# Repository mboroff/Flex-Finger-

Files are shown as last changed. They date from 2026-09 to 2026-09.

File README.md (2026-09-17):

# Flex Radio Mechanical Button Actuator (Linear Stepper Version)

A stepper-driven mechanism that physically presses the front-panel power button on a FlexRadio Flex 6xxx or 8xxx series software-defined radio (SDR), allowing it to be powered on, powered off, or force-reset (long hold) remotely from a Raspberry Pi.

This version replaces the original rotating servo-driven arm concept with a **28BYJ-48 stepper motor** paired with a linear rack-and-pinion finger, delivering high precision, smooth linear movement, and eliminating positional jitter.

---

## 📟 How the Radio's Button Behaves

The radio's front button behaves based on duration and state:

| Action | Result |
|---|---|
| Momentary press while off | Radio powers on |
| Momentary press while on | Radio powers off |
| Press and hold (while off) until the button glows white (~6.0s), then release | System factory reset |

The driver software handles two routines: a **momentary press** (power toggle) and a **long hold-then-release** (system reset). Both actions are "move finger onto button, dwell, move finger back," with the wait time being the only operational difference.

---

## 🏗️ Hardware & Wiring

### Parts List
- **Controller:** Raspberry Pi 4B (installed natively in `/home/pi`)
- **Motor Assembly:** 28BYJ-48 stepper motor + ULN2003 driver board
- **Enclosure & Mechanism:** 3D printed linear rack, pinion gear, and custom case (printed in PETG)
- **Fasteners:** M3 hardware for mounting the brackets near the radio panel
- **Power & Logic:** 4x jumper wires (Pi GPIO -> ULN2003 IN1-IN4), plus 5V/GND for the driver board.
  *(Note: Power the ULN2003 board from the Pi's 5V pin or a separate 5V supply if you see brownouts — the motor can pull enough current to reset the Pi on some setups).*

### Wiring Diagram

```
Raspberry Pi (BCM)      ULN2003 board
-------------------     -------------
GPIO17  -------------->  IN1
GPIO18  -------------->  IN2
GPIO27  -------------->  IN3
GPIO22  -------------->  IN4
5V      -------------->  VCC (motor supply)
GND     -------------->  GND
```

Pin mappings match the configuration variables in `software/stepper.py`. Update the code pins array if you wire the hardware differently.

---

## ⚙️ Mechanism & OpenSCAD Modeling

The 28BYJ-48 has a ~1:64 internal gear reduction, which provides high holding torque and precise positioning at low speed—ideal for a push-finger that needs to land reliably in the same spot every time. 

### 1. Actuator Mechanism (`finger.scad` / `gear.scad`)
- **The Linear Finger (`finger.scad`):** An L-shaped rack track with customized gear mesh teeth. The short edge of the "L" hangs over the front panel of the radio cabinet directly above the power button. 
- **The Drive Pinion Gear (`gear.scad`):** A custom 13-tooth gear designed with a specialized trapezoidal profile. It features a complete through-hole socket with a dual-flat profile (Double-D shape) matching the machined output shaft of the stepper motor perfectly.

### 2. Custom Electronics Enclosure (`enclosure.scad`)
- A 2.5-inch square custom travel box with integrated alignment pin standoffs configured specifically to securely seat the ULN2003 board.
- Includes built-in structural wire drop slits on opposite side walls and a custom friction-fit ventilation lid featuring a clean hexagonal cutout pattern for active airflow.

### Print Settings (PETG)
- **Nozzle Temp:** 230-240 °C, **Bed Temp:** 80-85 °C
- **Perimeters:** 3-4 walls, **Infill:** 20-25% (parts are low-load)
- **Supports:** No supports needed on any part as drawn (flat bottoms, bore facing up)
- Print the pinion gear with the bore axis vertical for precision accuracy on the Double-D profile.

---

## 💻 Software & Script Configuration

The control software is divided into a low-level driver and an automated action script wrapper:

*   `stepper.py` — Low-level motor driver. Takes step count + direction as parameters (CLI or import), and drives the ULN2003 half-step sequence.
*   `button_actions.py` — High-level automated actions (`power_toggle()`, `system_reset()`), containing your physical calibration constants.

### Direct Command-Line Examples

**Low-Level Rotation Example via `stepper.py`:**
```bash
python3 stepper.py --steps 512 --direction cw
```

**High-Level Button Automation Examples via `button_actions.py`:**
```bash
# Execute a standard power cycle toggle
python3 button_actions.py power

# Execute a system factory reset sequence (Requires terminal confirmation)
python3 button_actions.py reset
```

---

## 🔬 Calibration Procedure

Because the stepper motor is driven open-loop (no encoder), the "home" and "pressed" positions are step counts you calibrate once to match your printed geometry:

1. Home the linear finger by hand (with the motor unpowered) so it sits just clear of the physical radio button. Note this as position 0.
2. Run `stepper.py` with small step increments in the advance direction until you find the step count that fully depresses the button. Record this value as `PRESS_STEPS`.
3. Update `PRESS_STEPS` and `PRESS_DIRECTION` in `button_actions.py`.
4. Test the `power_toggle` action first (safe to get wrong). Only test the `system_reset` route once you are fully confident—an unintentional 6+ second hold will wipe your radio settings.

---

## 📂 Repository Structure

```
flex-button-bot/
├── README.md
├── hardware/
│   ├── enclosure.scad          # Custom ULN2003 case & hex lid
│   ├── finger.scad             # Linear moving rack-finger track
│   └── gear.scad               # Double-D shaft drive pinion gear
└── software/
    ├── stepper.py              # Low-level ULN2003 motor driver
    └── button_actions.py       # High-level macro action script
```

---

## ⚠️ Safety Notes

- **Stuck State Risk:** The reset action holds the button down for several seconds. If the software crashes or loses power while the arm is advanced, it could hold the radio in a perpetual reset loop. Consider a manual mechanical fail-safe (like a physical return spring) if running completely unattended.
- **Coil Management:** `stepper.py` always releases all coils in its `cleanup()` phase (including on unexpected crash exceptions), ensuring the motor never sits under continuous holding current when idle.

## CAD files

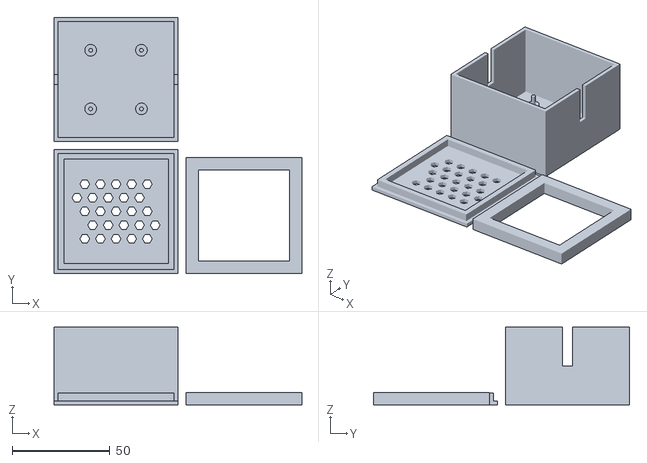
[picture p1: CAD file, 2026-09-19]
ControlBoxRing_google_V6.stl
126.9 x 131.0 x 39.7

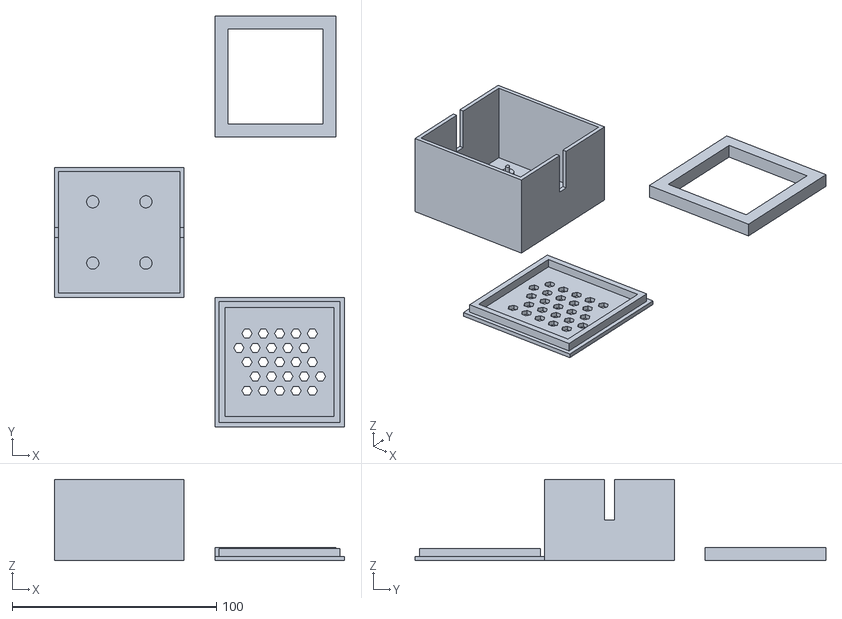
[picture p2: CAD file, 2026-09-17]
ControlBoxAndRing_google_V3.stl
142.0 x 201.2 x 39.7

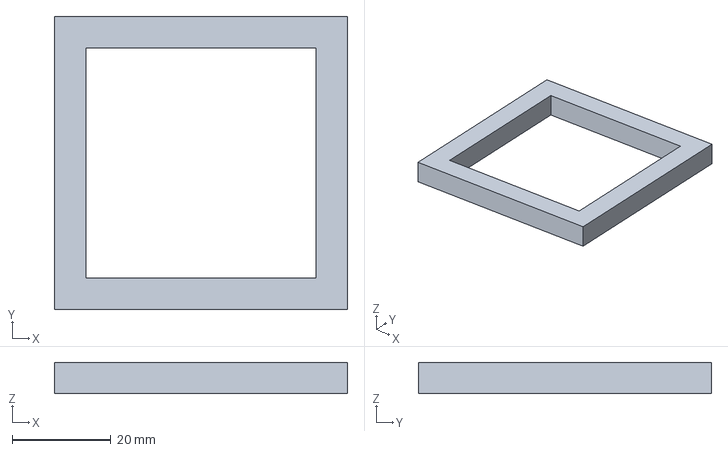
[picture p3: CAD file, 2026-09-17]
ControlBoxRing_google_V1.3mf
59.2 x 59.2 x 6.35 mm

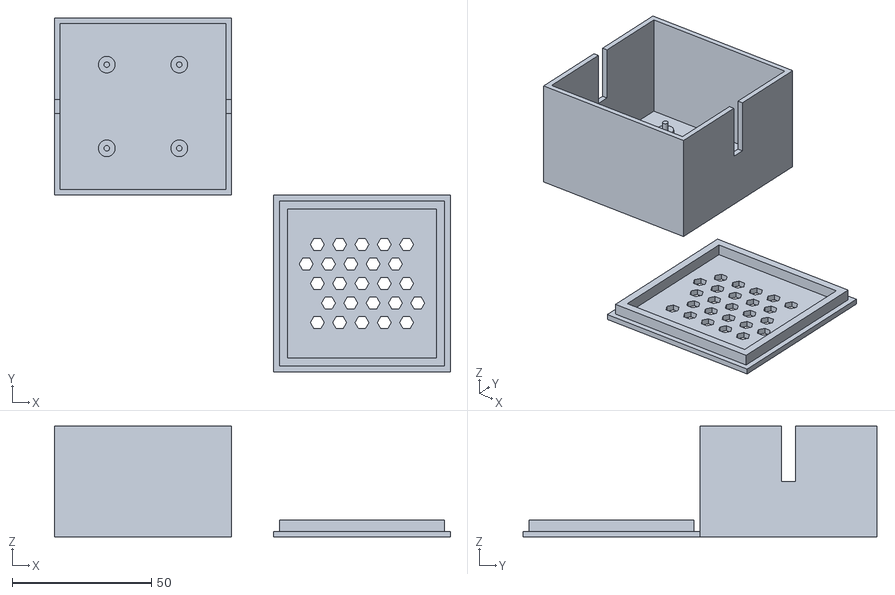
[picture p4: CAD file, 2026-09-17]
ControlBoard_Google_V2.stl
142.0 x 127.0 x 39.7

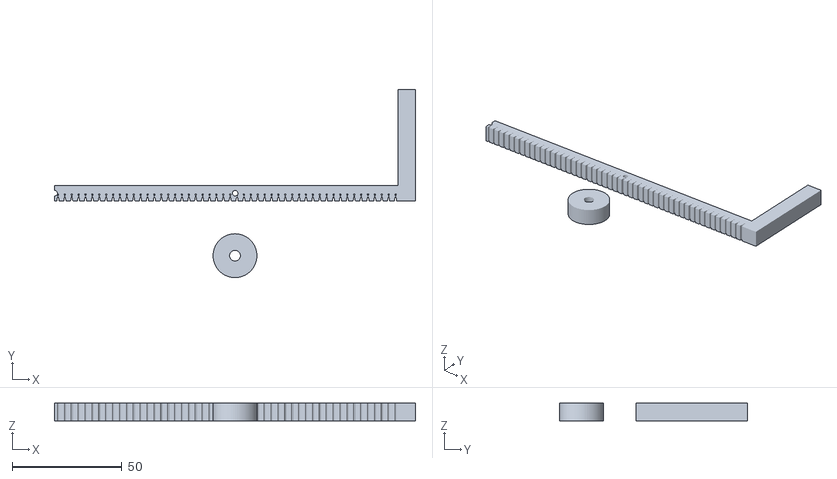
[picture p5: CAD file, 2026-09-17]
new_linear_set_google_v3.stl
164.6 x 85.8 x 8.00

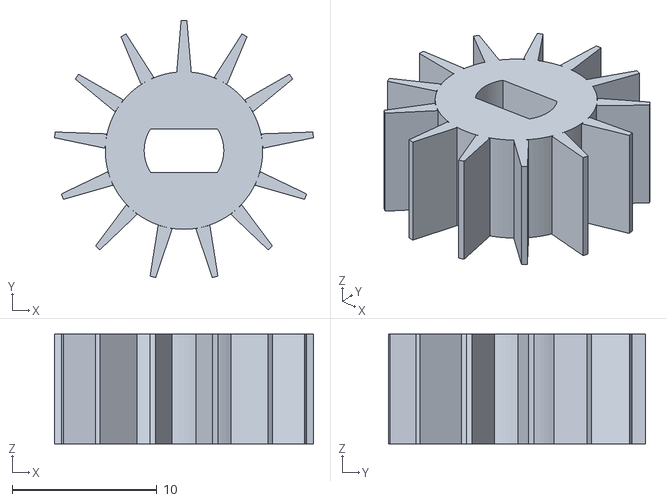
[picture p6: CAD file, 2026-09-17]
gear-2.stl
17.9 x 17.8 x 7.60

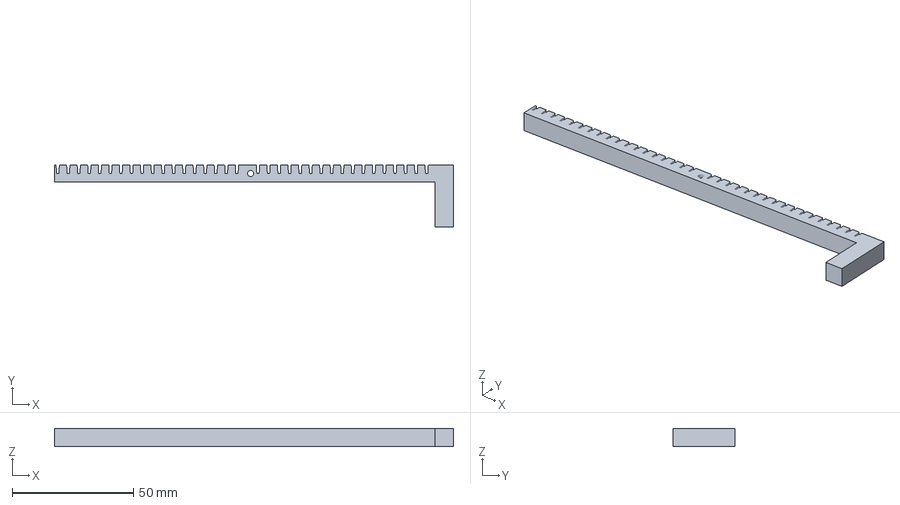
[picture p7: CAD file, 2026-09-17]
finger_V2.3mf
164.6 x 25.4 x 7.60 mm

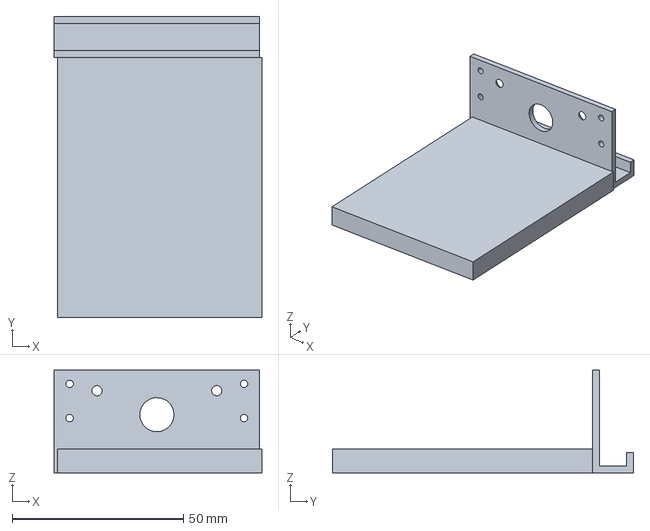
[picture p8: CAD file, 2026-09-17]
new bracket.3mf
60.7 x 88.0 x 30.0 mm

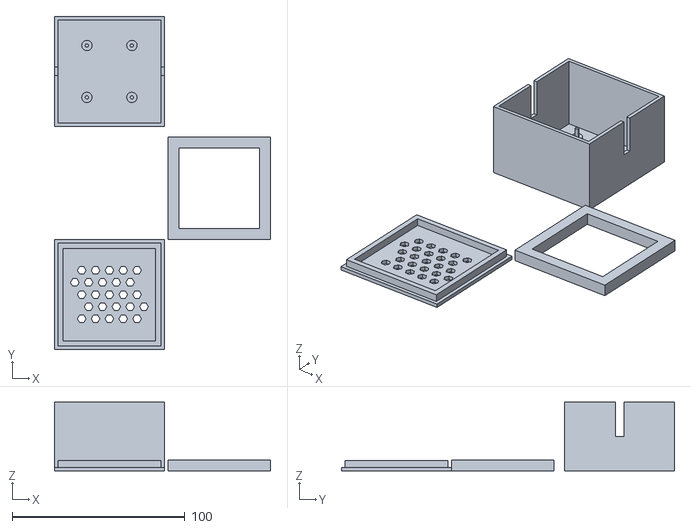
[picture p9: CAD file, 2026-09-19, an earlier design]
ControlBoxRing_google_V5.stl
124.9 x 192.5 x 39.7

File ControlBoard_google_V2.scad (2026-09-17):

// Custom Enclosure for ULN2003 Stepper Motor Driver Board
// Updated: Height raised to 1 9/16", snugger lid layers, and customized pin standoffs.

$fn = 40; // Circle smoothness

// --- PARAMETERS ---
box_size = 63.5;       // 2.5 inches square
box_height = 39.69;    // 1 9/16 inches overall height
wall_thick = 2.0;      // Outer shell wall thickness

// Board Mounting Dimensions (Calculated from ruler photos: ~26mm x 30mm)
pcb_hole_w = 26.0;     // Center-to-center hole spacing (Width)
pcb_hole_l = 30.0;     // Center-to-center hole spacing (Length)

standoff_h = 5.0;      // Height of main support base
standoff_dia = 6.0;    // Diameter of standoff base pillars
pin_h = 3.0;           // Height of alignment pin extending above standoff
pin_dia = 2.0;         // Diameter of alignment pin (fits standard PCB holes)

// Slits for wires (Halfway down opposite walls)
slit_w = 5.0;          // Width of wire drop slots
slit_depth = box_height / 2; 


// --- PRINT BED ARRANGEMENT (Z = 0) ---

// 1. Main Enclosure Base
translate([0, 0, 0]) {
    main_enclosure_base();
}

// 2. Enclosure Lid (Placed side-by-side with a 15mm layout gap)
translate([box_size + 15, 0, wall_thick]) {
    rotate([180, 0, 0]) {
        enclosure_lid();
    }
}


// --- MODULES ---

module main_enclosure_base() {
    difference() {
        // Outer Solid Box
        cube([box_size, box_size, box_height]);
        
        // Inner Hollow Space
        translate([wall_thick, wall_thick, wall_thick])
            cube([box_size - (wall_thick * 2), box_size - (wall_thick * 2), box_height]);
        
        // Wire Slit 1 (Left wall, centered)
        translate([-0.1, box_size / 2 - slit_w / 2, box_height - slit_depth])
            cube([wall_thick + 0.2, slit_w, slit_depth + 0.1]);
            
        // Wire Slit 2 (Right wall, centered)
        translate([box_size - wall_thick - 0.1, box_size / 2 - slit_w / 2, box_height - slit_depth])
            cube([wall_thick + 0.2, slit_w, slit_depth + 0.1]);
    }
    
    // Four Centered PCB Pin Standoffs
    translate([box_size / 2, box_size / 2, wall_thick]) {
        for (x = [-pcb_hole_w / 2, pcb_hole_w / 2]) {
            for (y = [-pcb_hole_l / 2, pcb_hole_l / 2]) {
                translate([x, y, 0]) {
                    // Standoff Support Base
                    cylinder(h = standoff_h, d = standoff_dia);
                    // Alignment Pin on top
                    translate([0, 0, standoff_h])
                        cylinder(h = pin_h, d = pin_dia);
                }
            }
        }
    }
}

module enclosure_lid() {
    lid_lip_height = 4.0; // Deeper friction path for a tight fit
    lid_clearance = 0.1;  // Reduced clearance for a tighter snap fit
    lip_thick = 3.0;      // Thicker wall layers on the inner lip profile
    
    // Main Lid Flat Plate
    difference() {
        cube([box_size, box_size, wall_thick]);
        
        // Ventilation Array (Hexagonal patterns centered on the top)
        translate([box_size / 2, box_size / 2, -0.1]) {
            for (xi = [-2:2]) {
                for (yi = [-2:2]) {
                    translate([xi * 8 + (yi % 2 * 4), yi * 7, 0])
                        cylinder(h = wall_thick + 0.2, r = 2.5, $fn = 6);
                }
            }
        }
    }
    
    // Reinforced Inner Alignment Lip 
    difference() {
        translate([wall_thick + lid_clearance, wall_thick + lid_clearance, -lid_lip_height])
            cube([box_size - (wall_thick * 2) - (lid_clearance * 2), box_size - (wall_thick * 2) - (lid_clearance * 2), lid_lip_height]);
        
        // Inner clearance cutout leaving a strong, thick tracking lip perimeter
        translate([wall_thick + lid_clearance + lip_thick, wall_thick + lid_clearance + lip_thick, -lid_lip_height - 0.1])
            cube([box_size - (wall_thick * 2) - (lid_clearance * 2) - (lip_thick * 2), box_size - (wall_thick * 2) - (lid_clearance * 2) - (lip_thick * 2), lid_lip_height + 0.2]);
    }
}

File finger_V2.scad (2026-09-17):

// ============================================================
// finger.scad
// Rack/finger extracted from finger_and_ger_google_V3_fixed.stl
// (the long L-shaped part, i.e. everything that is NOT the gear)
//
// Measured from the original STL (component 1 of the mesh):
//   - Overall length (long arm)      : 164.598 mm
//   - Toothed bar height             : 6.85 mm
//   - Bar extrusion thickness        : 7.598 mm  (same as the gear)
//   - Rack tooth (notch) pitch       : 2.6805 mm  -- VERY uniform
//     and consistent along the entire measured length (confirmed
//     by direct measurement of ~58 notches; this is not the source
//     of the skipping problem)
//   - Notch depth                    : 2.55 mm
//   - Notch opening width (at top)   : ~0.83 mm
//   - Notch bottom width             : ~0.59 mm
//   - Pivot/pin hole (through hole)  : dia. ~2.5 mm, located at
//                                       x=80.9, y=-3.4 from the
//                                       part's top-left corner
//   - Foot (short leg of the "L")    : 7.61 mm wide, originally
//                                       44.45 mm long (measured
//                                       from the top edge)
//
// Changes made (round 2, after test print):
//   1) Foot (short end) shortened by another 1/4" (6.35 mm), on
//      top of the 1/2" already removed:
//        44.45 -> 31.75 (round 1) -> 25.4 mm (this round)
//   2) The root-radius fix in gear.scad alone did not stop the
//      gear from catching the top of the next tooth, so the rack
//      pitch (tooth separation) is widened here instead, using the
//      gear's TIP circle rather than the root circle:
//          new_pitch = 2*pi*tip_r/teeth = 2*pi*8.99/13 = 4.348 mm
//      (up from the originally-measured 2.6805 mm -- a ~62% wider
//      spacing). The notch opening/bottom widths are scaled up by
//      the same ratio to keep the same proportions, and the notch
//      is cut deeper (3.45 mm, matching the gear's addendum height
//      of tip_r - root_r) so the now-taller, 1mm-longer gear teeth
//      can fully seat instead of skating across the top land and
//      catching the next tooth.
//   This is an empirical correction based on your test print --
//   print this version and check whether it still skips; the pitch
//   or notch depth may need another small nudge either way.
// ============================================================

/* [CONFIG] */

// --- Overall bar ---
total_length   = 164.598;  // full length of the part, end to end
bar_length     = 156.99;   // length of the toothed section (before the foot)
bar_height     = 6.85;     // height of the toothed bar (top edge = y0, bottom = -bar_height)
thickness      = 7.598;    // extrusion depth (Z), matches the gear thickness

// --- Rack teeth (notches cut into the top edge) ---
// Widened from the originally-measured 2.6805 mm to match the
// gear's tip-circle circumference (2*pi*8.99/13), since the root-
// circle-based pitch wasn't enough to stop the skipping in testing.
tooth_pitch        = 4.348;   // was 2.6805
tooth_depth        = 3.45;    // was 2.55 -- matches gear addendum height (tip_r - root_r)
tooth_top_width    = 1.35;    // was 0.83 -- scaled up with the wider pitch
tooth_bottom_width = 0.96;    // was 0.59 -- scaled up with the wider pitch
first_tooth_center = 1.334;   // x position of the first notch's center

// --- Pivot / pin hole ---
add_pivot_hole = true;
pivot_hole_x   = 80.9;    // measured from the left end of the part
pivot_hole_y   = -3.4;    // measured down from the top edge
pivot_hole_d   = 2.5;     // through-hole diameter

// --- Foot (short leg of the L-shape) ---
// Original measured length (from the top edge, y=0, down to the tip)
foot_length_original = 44.45;
// Shortened by 1/2" (round 1) then another 1/4" (round 2) per request
foot_length = foot_length_original - 12.7 - 6.35;   // = 25.4 mm

// Rendering smoothness
$fn = 60;

/* [END CONFIG] */

module tooth_notch() {
    translate([0, 0, -1])
        linear_extrude(height = thickness + 2)
            polygon(points = [
                [-tooth_top_width/2,    0],
                [-tooth_bottom_width/2, -tooth_depth],
                [ tooth_bottom_width/2, -tooth_depth],
                [ tooth_top_width/2,    0]
            ]);
}

module rack_teeth() {
    n = floor((bar_length - first_tooth_center) / tooth_pitch) + 1;
    for (i = [0 : n - 1]) {
        cx = first_tooth_center + i * tooth_pitch;
        // Skip whichever tooth would land on top of the pivot hole
        skip = add_pivot_hole && abs(cx - pivot_hole_x) < (pivot_hole_d/2 + 1.2);
        if (cx < bar_length && !skip)
            translate([cx, 0, 0])
                tooth_notch();
    }
}

module body() {
    union() {
        // main toothed bar, full length (top edge flush with the foot)
        translate([0, -bar_height, 0])
            cube([total_length, bar_height, thickness]);
        // foot: extra material hanging below the bar at the right end
        translate([bar_length, -foot_length, 0])
            cube([total_length - bar_length, foot_length - bar_height, thickness]);
    }
}

module pivot_hole() {
    translate([pivot_hole_x, pivot_hole_y, -1])
        cylinder(d = pivot_hole_d, h = thickness + 2);
}

module finger() {
    difference() {
        body();
        rack_teeth();
        if (add_pivot_hole)
            pivot_hole();
    }
}

finger();

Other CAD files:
ControlBoxAndRing_google_V4.scad
ControlBoxRing_google_V6.scad
ControlBoxAndRing_google_V3.scad
ControlBoxRing_google_V1.scad
ControlBoxRing_google_V1.stl
finger_V2.stl
gear-2.scad
new bracket.stl
new_linear_set_google_v3.scad

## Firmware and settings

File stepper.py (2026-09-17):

#!/usr/bin/env python3
"""
stepper.py - Drive a 28BYJ-48 stepper motor (via a ULN2003 driver board)
from a Raspberry Pi 4B.

Accepts number of steps and direction as parameters, either from the
command line or as an import.

CLI usage:
    python3 stepper.py --steps 512 --direction cw
    python3 stepper.py --steps 512 --direction ccw --delay 0.0015

Import usage:
    from stepper import rotate
    rotate(steps=512, direction="cw")
"""

import argparse
import time

try:
    import RPi.GPIO as GPIO
    _SIMULATE = False
except (ImportError, RuntimeError):
    # RuntimeError covers "not running on a Pi" on some RPi.GPIO builds
    GPIO = None
    _SIMULATE = True

# ---------------------------------------------------------------------------
# Configuration - edit to match your wiring
# ---------------------------------------------------------------------------
# ULN2003 IN1..IN4 -> Raspberry Pi BCM GPIO pins
PINS = [17, 18, 27, 22]

# Half-step sequence (8 steps/cycle). Half-stepping gives smoother motion
# and finer position resolution than full-stepping, at the same top speed.
# One full output-shaft revolution ≈ 2048 half-steps (28BYJ-48's ~1:64
# gearbox x 32 half-steps per internal motor revolution). Treat that as a
# rule of thumb, not a guarantee -- gear ratios vary slightly by batch.
HALF_STEP_SEQUENCE = [
    [1, 0, 0, 0],
    [1, 1, 0, 0],
    [0, 1, 0, 0],
    [0, 1, 1, 0],
    [0, 0, 1, 0],
    [0, 0, 1, 1],
    [0, 0, 0, 1],
    [1, 0, 0, 1],
]

DEFAULT_DELAY = 0.002  # seconds between half-steps; lower = faster, less torque


def _gpio_setup():
    if _SIMULATE:
        return
    GPIO.setmode(GPIO.BCM)
    for pin in PINS:
        GPIO.setup(pin, GPIO.OUT)
        GPIO.output(pin, 0)


def _gpio_cleanup():
    if _SIMULATE:
        return
    for pin in PINS:
        GPIO.output(pin, 0)
    GPIO.cleanup(PINS)


def rotate(steps: int, direction: str = "cw", delay: float = DEFAULT_DELAY) -> None:
    """
    Rotate the stepper a given number of half-steps.

    steps:     number of half-steps to move (non-negative int)
    direction: "cw" or "ccw"
    delay:     seconds to pause between each half-step; controls speed
    """
    if steps < 0:
        raise ValueError("steps must be >= 0")

    direction = direction.lower()
    if direction not in ("cw", "ccw"):
        raise ValueError("direction must be 'cw' or 'ccw'")

    sequence = HALF_STEP_SEQUENCE if direction == "cw" else list(reversed(HALF_STEP_SEQUENCE))

    _gpio_setup()
    try:
        for i in range(steps):
            step = sequence[i % len(sequence)]
            if not _SIMULATE:
                for pin, val in zip(PINS, step):
                    GPIO.output(pin, val)
            time.sleep(delay)
    finally:
        _gpio_cleanup()


def main():
    parser = argparse.ArgumentParser(description="Drive a 28BYJ-48 stepper motor via ULN2003.")
    parser.add_argument("--steps", type=int, required=True, help="Number of half-steps to move")
    parser.add_argument("--direction", choices=["cw", "ccw"], required=True, help="Rotation direction")
    parser.add_argument("--delay", type=float, default=DEFAULT_DELAY, help="Delay between half-steps, in seconds")
    args = parser.parse_args()

    if _SIMULATE:
        print("RPi.GPIO not available -- running in simulation mode (no pins driven).")

    rotate(args.steps, args.direction, args.delay)
    print(f"Moved {args.steps} half-steps {args.direction}.")


if __name__ == "__main__":
    main()

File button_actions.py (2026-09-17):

#!/usr/bin/env python3
"""
button_actions.py - High-level Flex 6800 button actions, built on stepper.py.

The radio's front button behaves like this:
    - Momentary press          -> toggles power on/off
    - Press and hold, then let
      go once it glows white   -> system reset

So both actions here are "move arm onto button, dwell, move arm back."
The only difference between a power toggle and a reset is the dwell time.

*** You must calibrate PRESS_STEPS for your own printed geometry before
    these will do anything useful -- see the README calibration section. ***

CLI usage:
    python3 button_actions.py power
    python3 button_actions.py reset

Import usage:
    from button_actions import power_toggle, system_reset
    power_toggle()
"""

import argparse
import time

from stepper import rotate

# ---------------------------------------------------------------------------
# Calibration constants -- tune these for your printed arm/hub geometry.
# See README.md "Calibration procedure".
# ---------------------------------------------------------------------------
PRESS_STEPS = 40          # half-steps from "home" to "button fully pressed"
PRESS_DIRECTION = "cw"    # direction that moves the arm onto the button
RELEASE_DIRECTION = "ccw" # direction that moves the arm back to home
STEP_DELAY = 0.002        # seconds between half-steps

RESET_HOLD_SECONDS = 6.0  # how long to hold before releasing for a reset;
                           # the radio's button glows white once this is
                           # long enough -- watch it the first few times
                           # and adjust rather than trusting this number


def _press():
    rotate(PRESS_STEPS, PRESS_DIRECTION, STEP_DELAY)


def _release():
    rotate(PRESS_STEPS, RELEASE_DIRECTION, STEP_DELAY)


def power_toggle():
    """Momentary press: turns the radio on if off, or off if on."""
    _press()
    _release()


def system_reset():
    """
    Press and hold until the button would glow white, then release.
    Only call this when you're confident PRESS_STEPS/PRESS_DIRECTION are
    correct -- an unwanted multi-second hold is a reset you didn't want.
    """
    _press()
    time.sleep(RESET_HOLD_SECONDS)
    _release()


def main():
    parser = argparse.ArgumentParser(description="Press the Flex 6800 power/reset button.")
    parser.add_argument("action", choices=["power", "reset"], help="Which action to perform")
    args = parser.parse_args()

    if args.action == "power":
        power_toggle()
        print("Power toggle complete.")
    else:
        confirm = input("This will hold the button for a system reset. Type 'yes' to continue: ")
        if confirm.strip().lower() == "yes":
            system_reset()
            print("Reset sequence complete.")
        else:
            print("Aborted.")


if __name__ == "__main__":
    main()

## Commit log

2026-09-17 Initial Upload
    [ControlBoard_Google_V2.stl, ControlBoard_google_V2.scad, finger_V2.3mf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]
2026-09-17 Add controlbox ring and node-red
    [ControlBoxAndRing_google_V3.scad, ControlBoxAndRing_google_V3.stl, ControlBoxRing_google_V1.3mf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]
2026-09-19 box changes
    [ControlBoxAndRing_google_V4.scad, ControlBoxRing_google_V5.stl, ControlBoxRing_google_V6.scad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]
